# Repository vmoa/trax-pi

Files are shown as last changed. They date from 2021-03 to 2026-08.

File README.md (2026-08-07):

# T-Rax Raspberry Pi Notes

This is the Raspberry Pi implementation of the T-Rax roof controller for the Robert Ferguson Observatory
[rfo.org](https://rfo.org).

This design is a logical follow-on to the [Arduino T-Rax](https://github.com/votmoa/trax-arduino) roof controller
created back in 2017 by Jim Finn, David Kensiski and Jay Pacheco.  The switch to the Raspberry Pi was driven by the desire
to implement an [ASCOM Alpaca](https://ascom-standards.org/Developer/Alpaca.htm) interface so that the roof
can be opened via automation through tools such as [NINA](https://nighttime-imaging.eu/) and the now defunct [ACP](https://acpx.dc3.com/)

Testing insturctions can be found in the [test plan](doc/TestPlan.md) document.

Version history can be found in [VERSION.md](VERSION.md).

# Table of Contents

1. [Theory of Operation](#theory-of-operation)
1. [Detailed Design](#detailed-design)
1. [Hardware Design](#hardware-design)
1. [Future Plans](#future-plans)
1. [Installation](#installation)
1. [GPIO Notes](#gpio-notes)

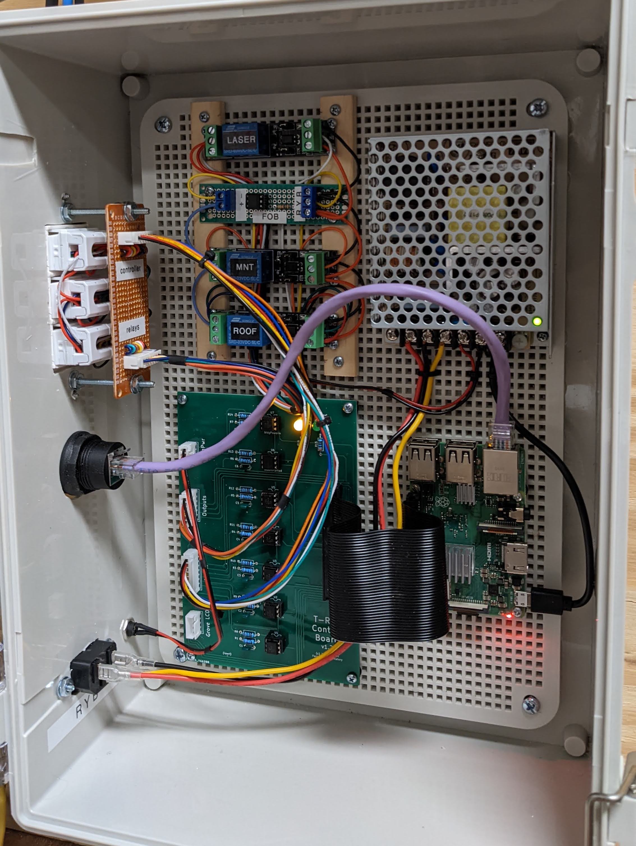
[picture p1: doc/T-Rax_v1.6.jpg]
T-Rax


# Theory of Operation

The server is written in Python 3 and utilizes only two external libraries:
[GPI Zero](https://gpiozero.readthedocs.io/en/stable/) to control the Raspberry Pi GPIO ports, and
[Flask](https://flask.palletsprojects.com/en/1.1.x/) to manage the web interface.  (Though Flask
has a bunch of prerequisites that also need to be loaded.)
The Browser panel is written in [HTML](https://www.w3schools.com/html/default.asp) using
Cascading Style Sheets ([CSS](https://www.w3schools.com/css/default.asp)) to control the apperance of the page, and
[Javascript](https://www.w3schools.com/js/default.asp) to handle communication and control the modal dialogs.

The overall software design is driven through interrupts -- there is no "main loop" as there was in the Arduino.
On start, the server sets  up logging, initializes each of the
GPIO pins, registers the web interface callbacks, then hands operation over to Flask to listen for incoming requests.

A separate bridge in `alpaca.py` exposes a minimal ASCOM Alpaca dome/shutter interface for automation clients. It accepts
`OpenShutter` and `CloseShutter` commands, reports `ShutterStatus`, and keeps control logic consistent with the browser
UI by routing Alpaca actuation through the same safety-checked roof toggle path.  Many thanks to
[Lena](https://github.com/lena-allie) for her [contributions](https://github.com/elenasch-playground/trax-pi/pull/1)
to the Alpaca driver.

There are three flavors of threads:

* Hardware input state changes trigger GPI Zero callbacks that execute in individual threads.
* Browser reqeusts trigger Flask actions that execute in separte threads.
* Finally an "update" thread executes every second to perform household chores.

There is a static html launcher page that is currently served directly by Apache.  This sets browser window size
(I don't think a window can reliably change its size once launched) and points it at http://trax:5000 which is where
trax.py is listening (by way of Flask).  This sends a template web page to paint the browser.  Once painted,
Javascript in the browser connects back to trax and and set up a server-sent events channel
([SSE](https://developer.mozilla.org/en-US/docs/Web/API/Server-sent_events))
so the server can pro-actively update the browser.  Browser javascript listens on this channel and paints the
display appropriately.  Browser buttons trigger async HTTP calls to varioius
trax URIs that perform an appropriate action, which in turn triggers an SSE response.

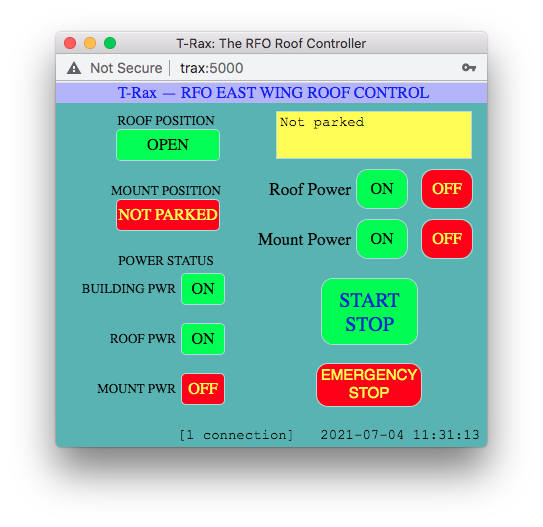
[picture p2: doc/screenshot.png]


Breaking this down, the connection flow is as follows:

1. User connects to http://trax and clicks the "Launch" button
1. Browser launches the T-Rax browser window pointing to http://trax:5000
1. Server sends static HTML, CSS and Javascript to paint the browser
1. After panting, browser javascript connects to http://trax:5000/connect to set up SSE channel

Then in normal operation:

* Server sends events via SSE when something changes
  * Browser executes javascript to handle the event
* Browser buttons send HTTP asynchronous requests to http://trax:5000/{whatever} to trigger actions
  * Sever performs the actions and responsds via SSE

The update thread is simply a thread that runs on startup to perform household chores and proactively update the
browser.  It then reschedules itself to run again one second later.  This thread updates the clock on the T-Rax
page to act as a hardbeat to confirm the server/browser SSE channel is active

# Software Design

The T-Rax software is structured around a Flask-based HTTP interface, GPIO abstractions, and a small set of cooperating threads.

* `trax.py` is the entry point. It initializes logging, constructs the GPIO objects, starts the periodic update thread, and registers the Flask routes for browser and Alpaca clients.
* `device.py` wraps `gpiozero` inputs and outputs in `Sensor` and `Control` classes. Inputs are configured with callbacks, and outputs include toggle timing and fob motion retry logic.
* `browser.py` implements the web UI callbacks. Each browser action checks safety interlocks, performs the required GPIO actuation, and sends status updates to the browser via SSE.
* `alpaca.py` implements a minimal ASCOM/Alpaca dome/shutter interface. It exposes `OpenShutter`, `CloseShutter`, `ShutterStatus`, discovery, and management endpoints while reusing the same roof safety and toggle logic as the browser UI.
* `sse.py` manages the server-sent event channel. The browser connects to `/connect` and receives live indicator updates, notices, and status changes.
* `test_mode.py` provides GPIO stubs for non-Pi environments so the software can run and be tested on a regular development machine.
* A recurring per-second housekeeping thread updates the browser clock, logs status, and handles timeouts (like laser auto-off).

Roof motion is coordinated by safety checks on building power, roof power, weather, mount park state, and the open/closed end-stop sensors. Both browser commands and Alpaca `OpenShutter`/`CloseShutter` flows delegate to the same underlying roof toggle path to keep behavior consistent.

# Hardware Design

The system is built around a [Raspberry Pi 3 B+](https://www.raspberrypi.org/products/raspberry-pi-3-model-b-plus/)
computer, though any Pi that sports the 40-pin GPIO header should work.  The header is routed to a custom circuit
board that splits out the GPIO inputs and outputs.  Output ports are fed to a 6-pin connetor that connects to the
relay board (see below).  Inputs are fed through RC low-pass filters (to reduce the effect
of electrical noise), current limiting resistors and optoisolators which ultimately deliver 3.3v to GPIO input ports.

External connectors are wired to jacks on a connecor board to maintain modularity.  Inputs are fed via an 8-pin
connector to the control board.  Outputs connect via a wiring harness from the 6-pin connector on the control board.
The roof and mount outputs directly feed relays to close a nomrally open circuit that in turn closes a relay circuit
in each of the remote roof and mount power controllers (not shown).

KiCad schematics and circuit board layout are available in the [KiCad](KiCad) subdirectory.
The full schematic is also available as a PDF: [TRax-Schematic.pdf](KiCad/TRax-Schematic.pdf)

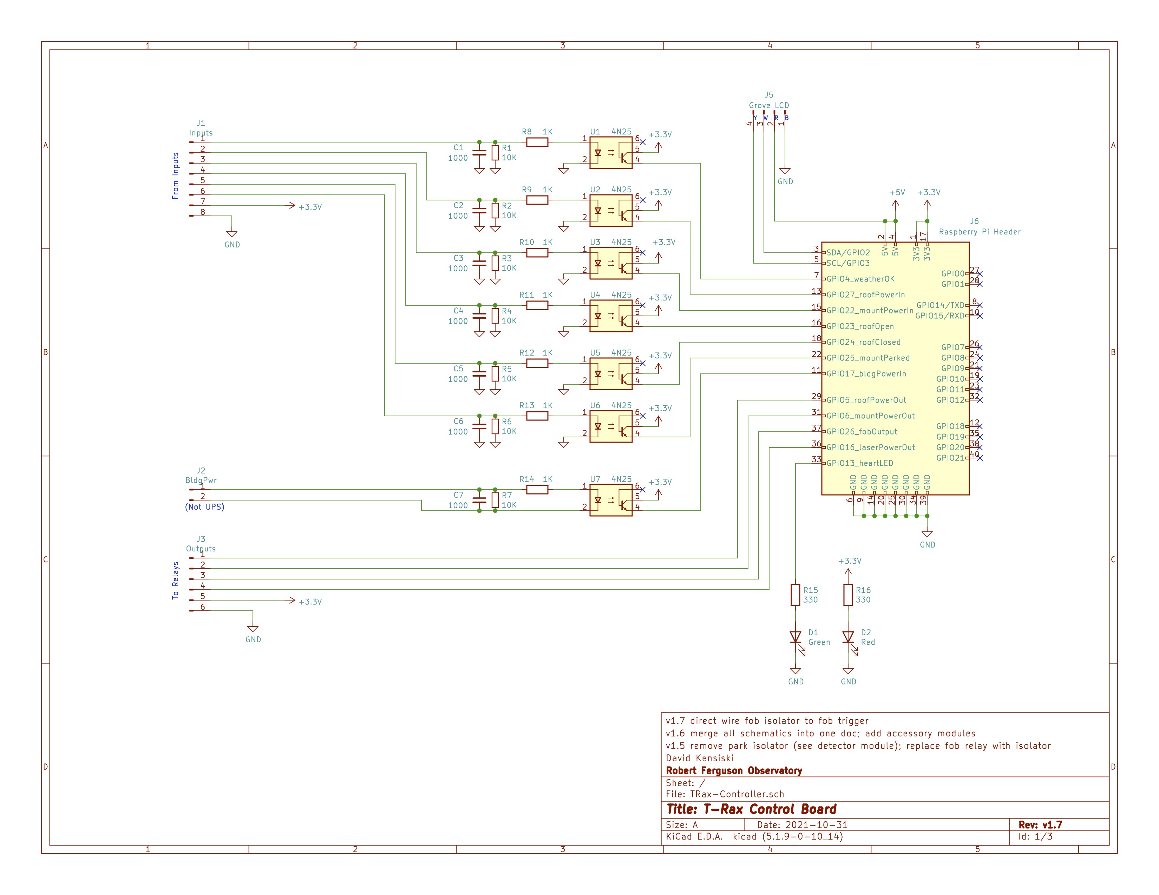
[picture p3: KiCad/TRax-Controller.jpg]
control board


### WeatherOK

This is the hardware signal from the [Boltwood Cloud Sensor](https://diffractionlimited.com/product/boltwood-cloud-sensor-ii/).
The configuration of the Clarity II software on the CCD PC determines what conditions trigger a weather alert.
The input feeds an optoisolator which triggers a GPIO port of the Raspberry Pi.  The Boltwood signal is active low
hence the name of the port is "weather OK".

### Mount Power

There are two ports used for the mount: mountPowerOut and mountPowerIn.  mountPowerOut triggers a
relay on the TRax Control Board which in turn closes a remote circuit in the Mount Power Controller under the telescope.
Power for that circuit comes from the Mount Power Controller.  The closing of that circuit triggers a relay in
the Mount Power Controller that powers the 12V supply that drives the mount.  A secondary contact on that relay 
closes the mountPowerIn circuit which is fed by 12V from the TRax Control Board.  That is fed through an optoisolator
to the GPIO port on the Raspberry Pi to provide positive feedback of mount power.

### Roof Power

Similarly there are two ports used for roof power: roofPowerOut and roofPowerIn.  These are designed
virtually identically to the mount power ports described above.

### Open / Close

Mounted on the roof rails are magnetic reed relays (alarm sensors) that engage when the roof is
either fully open or fully closed.  The TRax Control Board provides 12V to these relays through the Open/Close port.
Singal from these are fed through optoisolators to the GPIO ports on the Raspberry Pi.

### Fob

The fob is an actual gate controller fob (Model LM123) that has been removed from it's case and wired to a terminal
block.  T-Rax provides the fob with 12v DC to "replace" the battery, and has the contacts from it's top button wired
so we can trigger the fob on command.  This trigger was orignally wired to a relay but the contact bounce caused
the fob to trigger several times when the relay was engaged.  We instead use an optoisolator which avoids the
bounce, but care must be taken to maintain polarity with respect to the isolator.  The button is also an active
part of an RF circuit (433.92 MHz) so cable length should be limited.

### Park Detector

Because there is no place on the mount where physical relays can be mounted to postively confirm
park position, we have built a laser park sensor.  This consists of a low power laser on the mount dovetail plate and
a corresponding laser detector attached to the north wall.  These are aligned so that the detector triggers only when
the mount is in park position.  Both laser and detector are connected to the park port through an RJ-11 splitter.

The laser output from the control board triggers a relay with provides 12vdc (switched) to the park connector.
This 12v powers voltage regulators in both moduels that provides the 5v necessary to power the devices.  When
power is applied, the laser illuminates while simultaneously the park detector powers up.  If the telescope is
parked, the beam of the laser illuminates the detector.  The detector is active low so the signal is inverted by
a 2N2222 transistor and triggers an optoisolator which closes the park input.  If the telescope is not parked,
the laser does not illuminate the detector and the optoisolator output remains open.

Using 12v to power 5v circuitry avoids the issue of voltage drop over long DC runs that we've seen with the "friggin' laser".

### Building Power

Since TRax is fed via UPS power, the building power port is fed by a 12V wall wart plugged into
a non-UPS powered outlet.  When there is a power failure, this voltage drops and we are able to detect the outage to
prevent opening (but not closing!) of the roof.  The 12V is fed through an optoisolator to the GPIO port on the
Raspberry Pi.  It should be noted that this entire 12V source is isolated from the rest of the TRax circuit.  The
input side of the optoisolator is feed directly from this 12V source and (unlike the other circuits) is *not*
connected to the Control Board ground.

### Heart & Power LEDs

The heartbeat LED is fed directly from a GPIO port on the Raspberry Pi (through a current limiting resistor) and
flashes to indicate that the TRax software is running and healthy.  The power LED is fed by the 3.3V power rail on
the Raspberry Pi (thorugh a current limiting resistor) and indicates that the Raspberry Pi has power.

### Grove LCD

This port is wired for the [I2C](https://www.circuitbasics.com/basics-of-the-i2c-communication-protocol/)
serial bus required by the [Grove RGB LCD](https://wiki.seeedstudio.com/Grove-LCD_RGB_Backlight/).  We route the `SDA`
and `SCL` ports from the Raspberry Pi as well as the requisite ground and +5V.  Note that this uses +5V, not the +3.3V
of the rest of the controller.

As of this writing the Python code does not yet implement the Grove LCD.

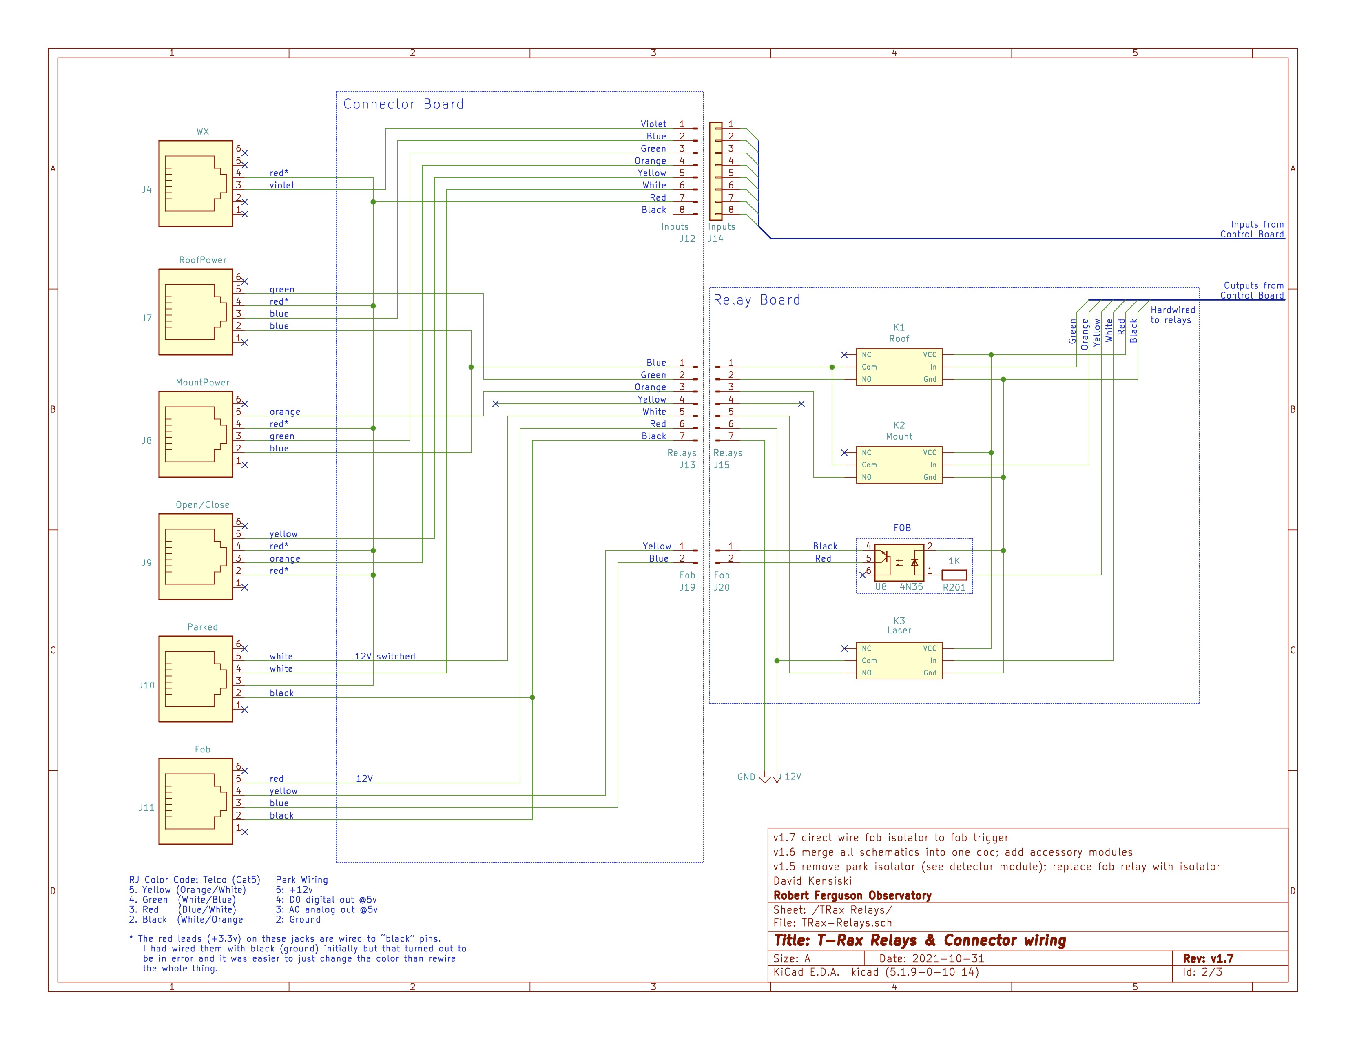
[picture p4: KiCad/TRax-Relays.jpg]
relay board


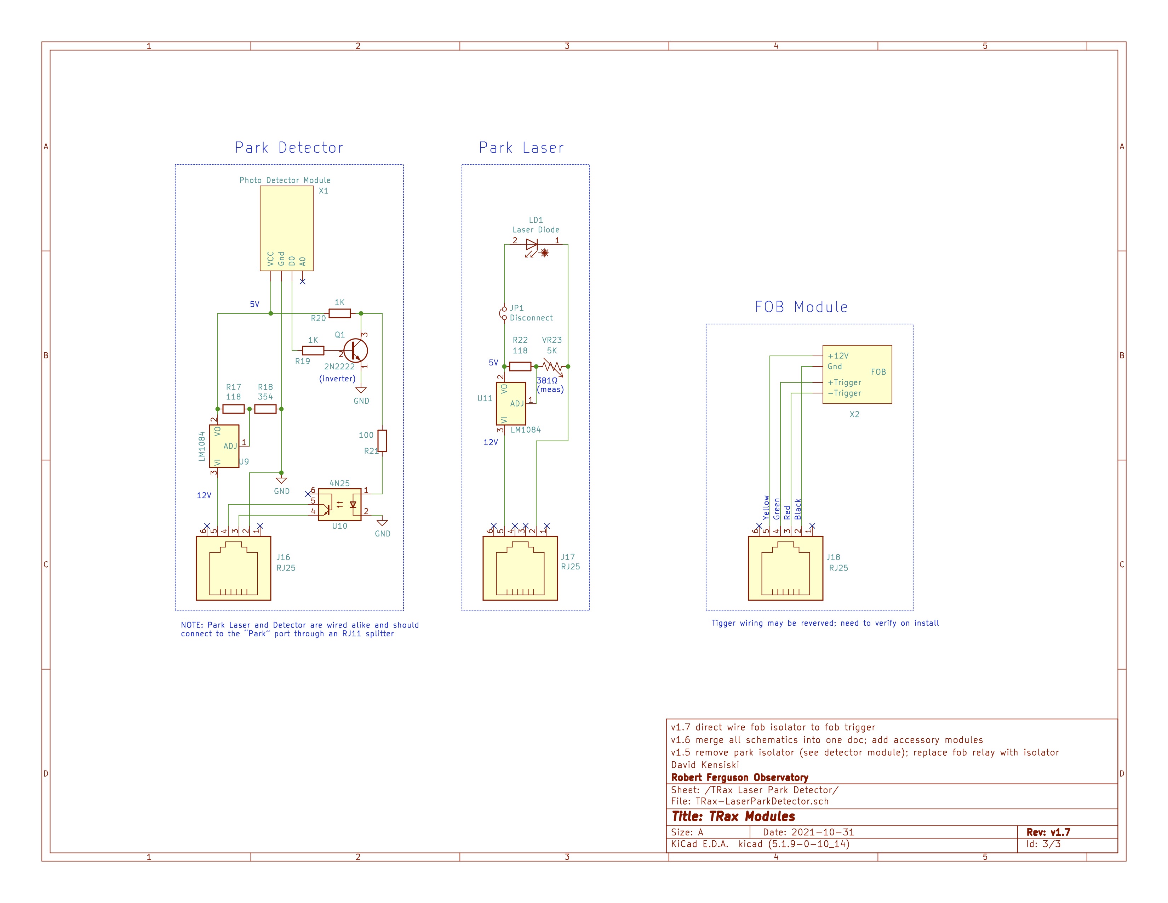
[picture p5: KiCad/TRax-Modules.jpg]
modules


# Future Plans

- [ ] Use md5 hashed password instead of hard coding
- [ ] Implement all logging using Flask's logging wrapper (evaluate how useful)
- [ ] Switch from Flask web server to Apache/WCGI
- [ ] Implement ASCOM/Alpaca
- [ ] Implement the Grove LCD
- [ ] Make multi-user (eg: for emergency override, notifications)

## Notes on the ASCOM/Alpaca implementation

From: Roger Boulanger <rogerjb88@gmail.com>\
Date: Fri, Sep 19, 2025 at 2:40 PM\
Subject: East Wing Automation.\
To: David Kensiski <David@kensiski.org>\

Hi Dave:

Following our brief discussion on this subject a couple days ago, I'd like to confirm a couple things.

First, T-Rax will need to include a Dome Alpaca Server which accepts "OpenShutter" and "CloseShutter" commands to open & close the roof.

In addition, it will need to expose the ShutterStaus ("ShutterOpen" or "ShutterClosed"). While NINA will send out Discord notifications for both conditions, it will only look for a "ShutterOpen" condition before attempting to do anything with the telescope.

How do you feel about having T-Rax automatically turning on Mount Power whenever the roof is fully open and off when it isn't? Otherwise we'd have to use one of the other standard ASCOM Dome commands to do this from NINA. Not impossible but just a little weird.

A benefit to SkyX users would be one less Checklist step to execute;-)

Roger

# Installation

Installation instructions reside in their own file: [INSTALL.md](INSTALL.md)

# GPIO Notes

General Purpose Input/Output

GPIO Pinout Diagram


## Input GPIO ports (sensors)

* GPIO4: weatherOK = newSensor(pin=4);
* GPIO17: bldgPowerIn = newSensor(pin=17);
* GPIO27: roofPowerIn = newSensor(pin=27);
* GPIO22: mountPowerIn = newSensor(pin=22);
* GPIO23: roofOpen = newSensor(pin=23);
* GPIO24: roofClosed = newSensor(pin=24);
* GPIO25: mountParked = newSensor(pin=25);

## Output GPIO ports (controls)

* GPIO5: roofPowerOut = newControl(pin=5)
* GPIO6: mountPowerOut = newControl(pin=6)
* GPIO26: fobOutput = newControl(pin=26)
* GPIO13: heartLed = newControl(pin=13)
* GPIO16: laserPowerOut = newControl(pin=16)

| GPIO | Function | T-Rax |
| ---- | --- | ----- |
| 2 | I2C | LCD |
| 3 | I2C | LCD |
| 4 | | weatherOK |
| 17 | SPI1 | bldgPowerIn |
| 27 | | roofPowerIn |
| 22 | | mountPowerIn |
| 10 | SPI0 |  |
| 9 | SPI0 |  |
| 11 | SPI0 |  |
| 0 | I2C | LCD |
| 5 | | roofPowerOut |
| 6 | | mountPowerOut |
| 13 | PWM | Heart LED |
| 19 | PWM,SPI1 |  |
| 26 | | fobOutput |
| | | |
| 14 | Serial |  |
| 15 | Serial |  |
| 18 | PWM,SPI1 |  |
| 23 | | roofOpen |
| 24 | | roofClosed |
| 25 | | mountParked |
| 8 | SPI0 |  |
| 7 | SPI0 |  |
| 1 | I2C | LCD |
| 12 | PWM |  |
| 16 | SPI1 | laserPowerOut |
| 20 | SPI1 |  |
| 21 | SPI1 |  |

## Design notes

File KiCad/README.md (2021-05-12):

# KiCad Files

[KiCad](https://kicad.org/) (pronounced KEY-cad) is a Cross Platform and Open Source Electronics Design Automation Suite.

This directory contains the design files for the TRax hardware. Source is KiCad but I have exported as PDF/JPG.

* **TRax-BlockDiagram** Work in progress to document the overall system
* **TRax-Controller** Schematic and PCB layout of the controller board
* **TRax-Relays** TRax relays and connector woring

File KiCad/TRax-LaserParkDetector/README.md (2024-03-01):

# Park Detector KiCad files

This is a static copy of the [TRax-Schematic](../TRax-Schematic) project at v1.7 with everythig stripped
out except for the park detector.  Reason being that KiCad doesn't appear to have a way to lay out a board
based on only part of a schematic.

**Caveat Emptor**: Changes made to the main schematic will have to be replicated here.  (Boo...)

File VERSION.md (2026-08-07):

# T-Rax Version History

| Version | Date | Notes |
|---|---|---|
| v.1.1.0 | 2026-08-06 | Add ASCOM Alpaca dome/shutter interface |
| v.1.0.8 | 2023-06-21 | Implement laser timeout for Emergency Override |
| v.1.0.7 | 2021-10-17 | Fixed toggleFob() roof logic |
| | | Increased fob_wait to 3 seconds |
| | | Better roof position reporting |
| | | Added "confused" roof state |
| v.1.0.6 | 2021-09-28 | Replace toggleThrice() with fob.toggleFob(), using callbacks instead of a timer loop |
| v.1.0.5 | 2021-08-22 | In emergency override, checkPark toggles laser indefinitely, and updateBrowser reports actual park position |
| v.1.0.4 | 2021-07-11 | Added toggleThrice() to make sure fob activates roof |
| | | Updated installation instructions |
| v.1.0.3 | 2021-07-07 | Removed pedantic power checks |
| | | Created test plan |
| | | mount and roof should not be reverse logic |
| | | pulled custom relay symbol into library |
| | | pass version to browser and report on connect |
| v.1.0.2 | 2021-06-05 | created service start script |
| | | added connection count to ticker |
| | | add file locking to prevent multiple copiesA |
| | | lots of documentation updates |
| | | lots of schematic updates |
| v.1.0 | 2021-04-25 | Released version 1.0; see `git log` for previous |

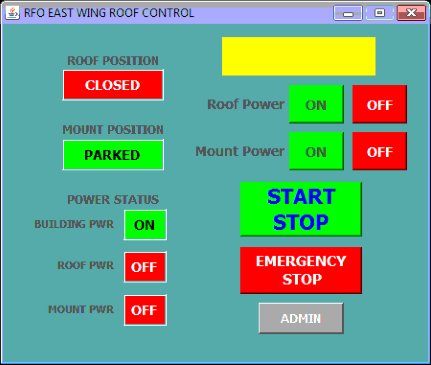
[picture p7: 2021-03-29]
doc/java.png

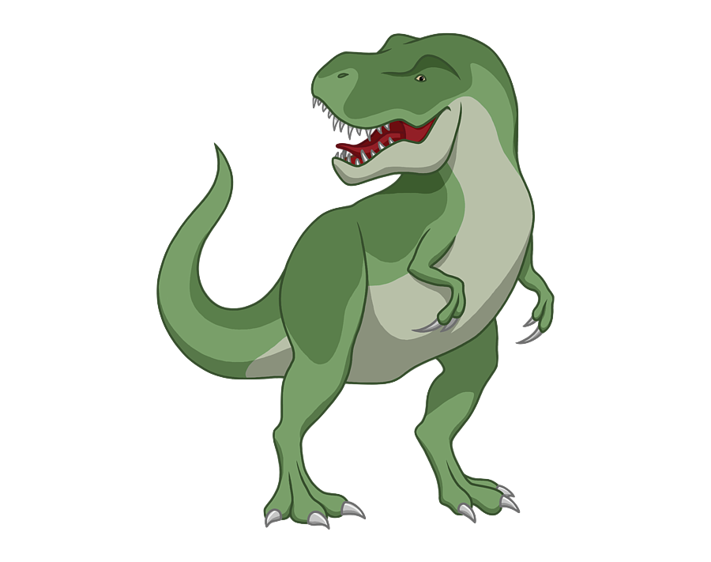
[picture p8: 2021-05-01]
static/trex-clipart.png

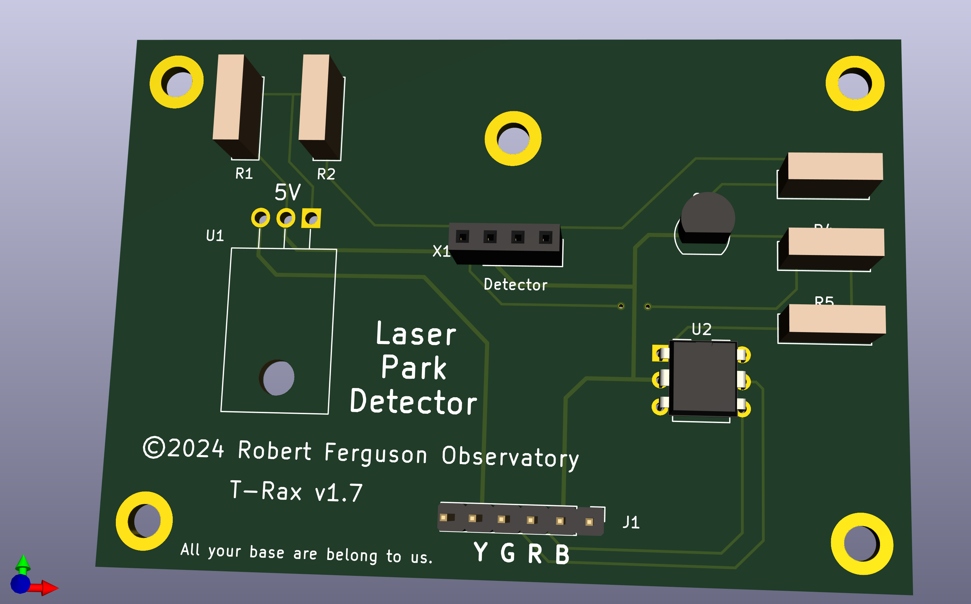
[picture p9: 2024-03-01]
KiCad/ParkDetector_3d.png

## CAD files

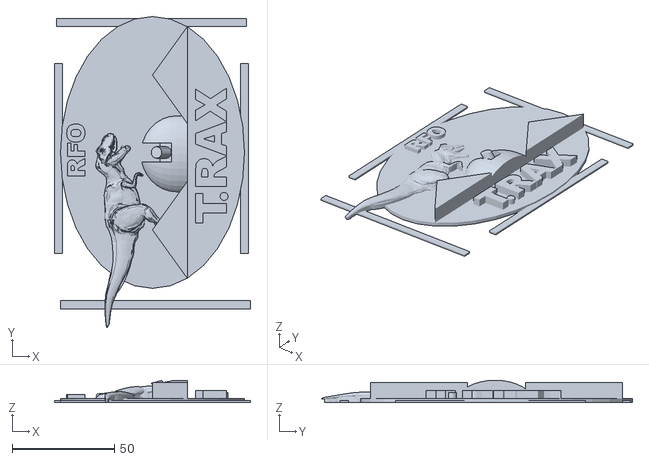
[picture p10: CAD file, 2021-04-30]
doc/3d_print/rfo.stl
96.0 x 152.1 x 11.0

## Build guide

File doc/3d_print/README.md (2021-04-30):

# 3D Printer Design for T-Rax Logo

These designs were produced and 3D printed by Aaron "Jay" Pacheco (joaquemin@gmail.com) for the
original Arduino T-Rax. He has since moved away but has graciously shared them with us.

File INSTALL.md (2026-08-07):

# Installation Notes

* Burn an SD card from a Rapberry Pi OS (32-bit) image

* Boot and configure; recommendations:
  * **Wired network**, wifi okay for testing
  * **Static IP** or statically assigned DHCP
  * **Local timezone** (logs easier to parse)

* Further configuration: `sudo raspi-config`
  * Set hostname: System Options --> Hostname
  * Enable SSH: Interface Options --> SSH
  * Disable graphical interface: System Options --> Boot / Auto Login --> Console
    * Optional, but recommended for production

* Change system editor to vim; nano should die
```
sudo update-alternatives --set editor /usr/bin/vim.tiny
```

* Update system
```
sudo apt-get update
sudo apt-get upgrade
```

* Install prerequisites
```
sudo apt-get install apache2
```

* Create trax user
```
sudo useradd -d /home/trax -s /bin/bash -m trax
sudo usermod -G gpio trax
```

* Fetch trax code
```
cd /home/trax
sudo -u trax git clone https://github.com/vmoa/trax-pi.git
```

* Clean up stuff that should be part of a trax setup script
```
sudo touch /tmp/trax.lock 
sudo chmod 666 /tmp/trax.lock 
sudo touch /var/log/trax.log
sudo chown trax /var/log/trax.log
#
sudo cp /home/trax/trax-pi/static/index.html /var/www/html/
sudo cp /home/trax/trax-pi/static/trex-clipart.png /var/www/html/
#
sudo cp /home/trax/trax-pi/static/trax.service /etc/systemd/system/
sudo systemctl enable trax.service
sudo systemctl start trax.service
```

* RFO specific stuff
  * Add an admin user or two with SSH credentials (TODO)
  * Configure static route for VPN (TODO)

* Point a browser at your system and verify!

* Reboot and verify auto-start
```
sudo reboot
```

# Appendix

* Debugging commands if things go south
```
systemctl status trax.service
systemctl list-units | grep trax
journalctl -u trax.service
```

* Add another user
```
NEWUSER=dlk
sudo useradd -d /home/$NEWUSER -s /bin/bash -m $NEWUSER
sudo usermod -G adm,gpio,sudo $NEWUSER
sudo passwd $NEWUSER
sudo -u $NEWUSER mkdir ~$NEWUSER/.ssh
sudo -u $NEWUSER vi ~$NEWUSER/.ssh/authorized_keys
sudo -u $NEWUSER chmod 700 ~$NEWUSER/.ssh
```

# Alpaca (ASCOM) API

This project exposes a minimal ASCOM Alpaca-compatible dome interface (shutter-only) at `/api/v1/dome/0`.

Quick test examples (once `trax` is running):

```
# Check connected
curl http://<host>:5000/api/v1/dome/0/connected

# Open shutter
curl http://<host>:5000/api/v1/dome/0/openshutter

# Close shutter
curl http://<host>:5000/api/v1/dome/0/closeshutter

# Query shutter status (ASCOM ShutterState enum: 0=Open, 1=Closed, 2=Opening, 3=Closing, 4=Error)
curl http://<host>:5000/api/v1/dome/0/shutterstatus
```

The API returns JSON in the Alpaca format with `Value`, `ClientTransactionID`, `ServerTransactionID`, `ErrorNumber`, and `ErrorMessage` fields.

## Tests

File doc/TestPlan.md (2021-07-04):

# Instructions for Testing T-Rax

This is a test suite to run through to check for regressions when making
changes to the T-Rax code.  This requires the simulator and should work
with it either connected through the RJ11 cables or directly to the
controller board.
(Note that instrucitons were initally written using the sensor cables and
have not yet been tested with the direct controller connection.)

[Return](../README.md) to the T-Rax main page.

---

_TODO_: Add wiring details and options

Note on `BldgPwr`: The pushbutton switch is used when connecting directly to the controller board;
the toggle is used when connecting via sensor cables.

1. Start the version of trax.py you wish to test.
   * This might require stopping the auto-boot version:
      `sudo systemctl stop trax`
   * Simulator mode gives you more time to push buttons:
      `sudo ./trax.py --simulator`

1. Set all simulator buttons and switches to __OFF__ (including `BldgPwr` toggle)

1. Point a browser to http://trax (or via IP) and click the image to open T-Rax browser window
   * Notice briefly reads `Connecting to T-Rax`, then `Connected!` and a welcome and version number
   * Roof position reads `MIDWAY`
   * Mount position reads `UNKNOWN`
   * All status indicators read `OFF`
   * Time should be incrementing

1. Depress "Close" button
   * ROOF POSITION reads `CLOSED`

1. Turn `BldgPwr` __ON__
   * BUILDING PWR reads `ON`

1. Click MOUNT POSITION `UNKNOWN` indicator
   * Notice reads `Laser ON checking park`
   * Park LED (red) illuminates briefly
   * After _simulatordelay_ seconds, LED turns off and
     * Notice reads `Not parked`
     * MOUNT POSITION reads `NOT PARKED`
   * After _shortdelay_ seconds, MOUNT POSITION background changes to orange
   * After _longdelay_ seconds, MOUNT POSITION changes to `UNKNOWN`

1. Click MOUNT POSITION `UNKNOWN` indicator
   * Notice reads `Laser ON checking park`
   * Park LED (red) illuminates briefly
   * While LED illuminated, depress "Park" button (repeat if you missed it)
     * Park LED turns off
     * Notice reads `Parked`
     * MOUNT POSITION reads `PARKED`
   * After _shortdelay_ seconds, MOUNT POSITION background changes to pale yellow
   * After _longdelay_ seconds, MOUNT POSITION changes to `UNKNOWN`

1. Click `START STOP`
   * Noice reads `Cannot open roof: roof power is not on`

1. Click Roof Power `ON`
   * Notice reads `Turning on roof power`
   * RoofPwr LED (yellow) illuminates

1. Depress "RoofPwr" button
   * ROOF PWR reads `ON`

1. Click Mount Power `ON`
   * Notice reads `Cannot turn on mount: roof is not open`

1. Click `START STOP`
   * Notice reads `Cannot open roof: Weather not OK`

1. Depress "WX" button

1. Click `START STOP`
   * Notice flashes `Laser ON checking park` and Park LED (red) illuminates briefly
     (might be too fast to notice, but we tested above)
   * MOUNT POSITION reads `PARKED`
   * Noitce reads `Toggling fob (opening roof)`
   * FOB LED (blue) illuminates briefly
   * A lot of things happen at once -- repeat this step as necessary to confirm operation

1. Undpress "Close" button
   * ROOF POSITION reads `MIDWAY`

1. Click `START STOP`
   * Notice reads `Toggling fob (roof midway)`
   * FOB LED (blue) illuminates briefly

1. Click `EMERGENCY STOP`
   * Notice reads `EMERGENCY STOP! Turning off roof power`
   * RoofPwr LED (red) extinguishes

1. Undepress RoofPwr button
   * ROOF PWR reads `OFF`

1. Click Roof Power `ON`
   * Notice reads `Turning on roof power`
   * RoofPwr LED (red) extinguishes

1. Depress RoofPwr button
   * ROOF PWR reads `ON`

1. Depress "Open" button
   * ROOF POSITION reads `OPEN`

1. Click Mount Power `ON`
   * Notice reads `Turning on mount power`
   * MntPwr LED (green) illuminates

1. Depress "MntPwr" button
   * MOUNT PWR reads `ON`

1. Undepress "Park" button

1. Click `START STOP`
   * Notice reads `Laser ON checking park` and Park LED (red) illuminates
   * After _shortdelay_ seconds, MOUNT POSITION reads `NOT PARKED`
   * Notice reads `Cannot close roof: mount must be parked first`

1. Depress "Park" button

1. Click `START STOP`
   * Notice flashes `Laser ON checking park` and Park LED (red) illuminates briefly, MOUNT POSITION reads `PARKED`
   * Notice reads `Cannot close roof: mount power is on`

1. Click Mount Power `OFF`
   * MntPwr LED (yellow) turns off

1. Undepress "MntPwr" button

1. Click `START STOP`
   * Notice flashes `Laser ON checking park` and Park LED (red) illuminates briefly,  MOUNT POSITION reads `PARKED`
   * Noitce reads `Toggling fob (closing roof)`
   * FOB LED (blue) illuminates briefly

1. Undepress "Open" button
   * ROOF POSITION reads `MIDWAY`

1. Depress "Close" button
   * ROOF POSITION reads `CLOSED`

1. Click Roof Power `OFF`
   * RoofPwr LED extinguishes

1. Undepress "RoofPwr" button
   * ROOF PWR read `OFF`

1. Stop the test version of the software by typing Ctrl-C in the shell where you started it
   * Restart the auto-start version if stopped above: 
      `sudo systemctl start trax`

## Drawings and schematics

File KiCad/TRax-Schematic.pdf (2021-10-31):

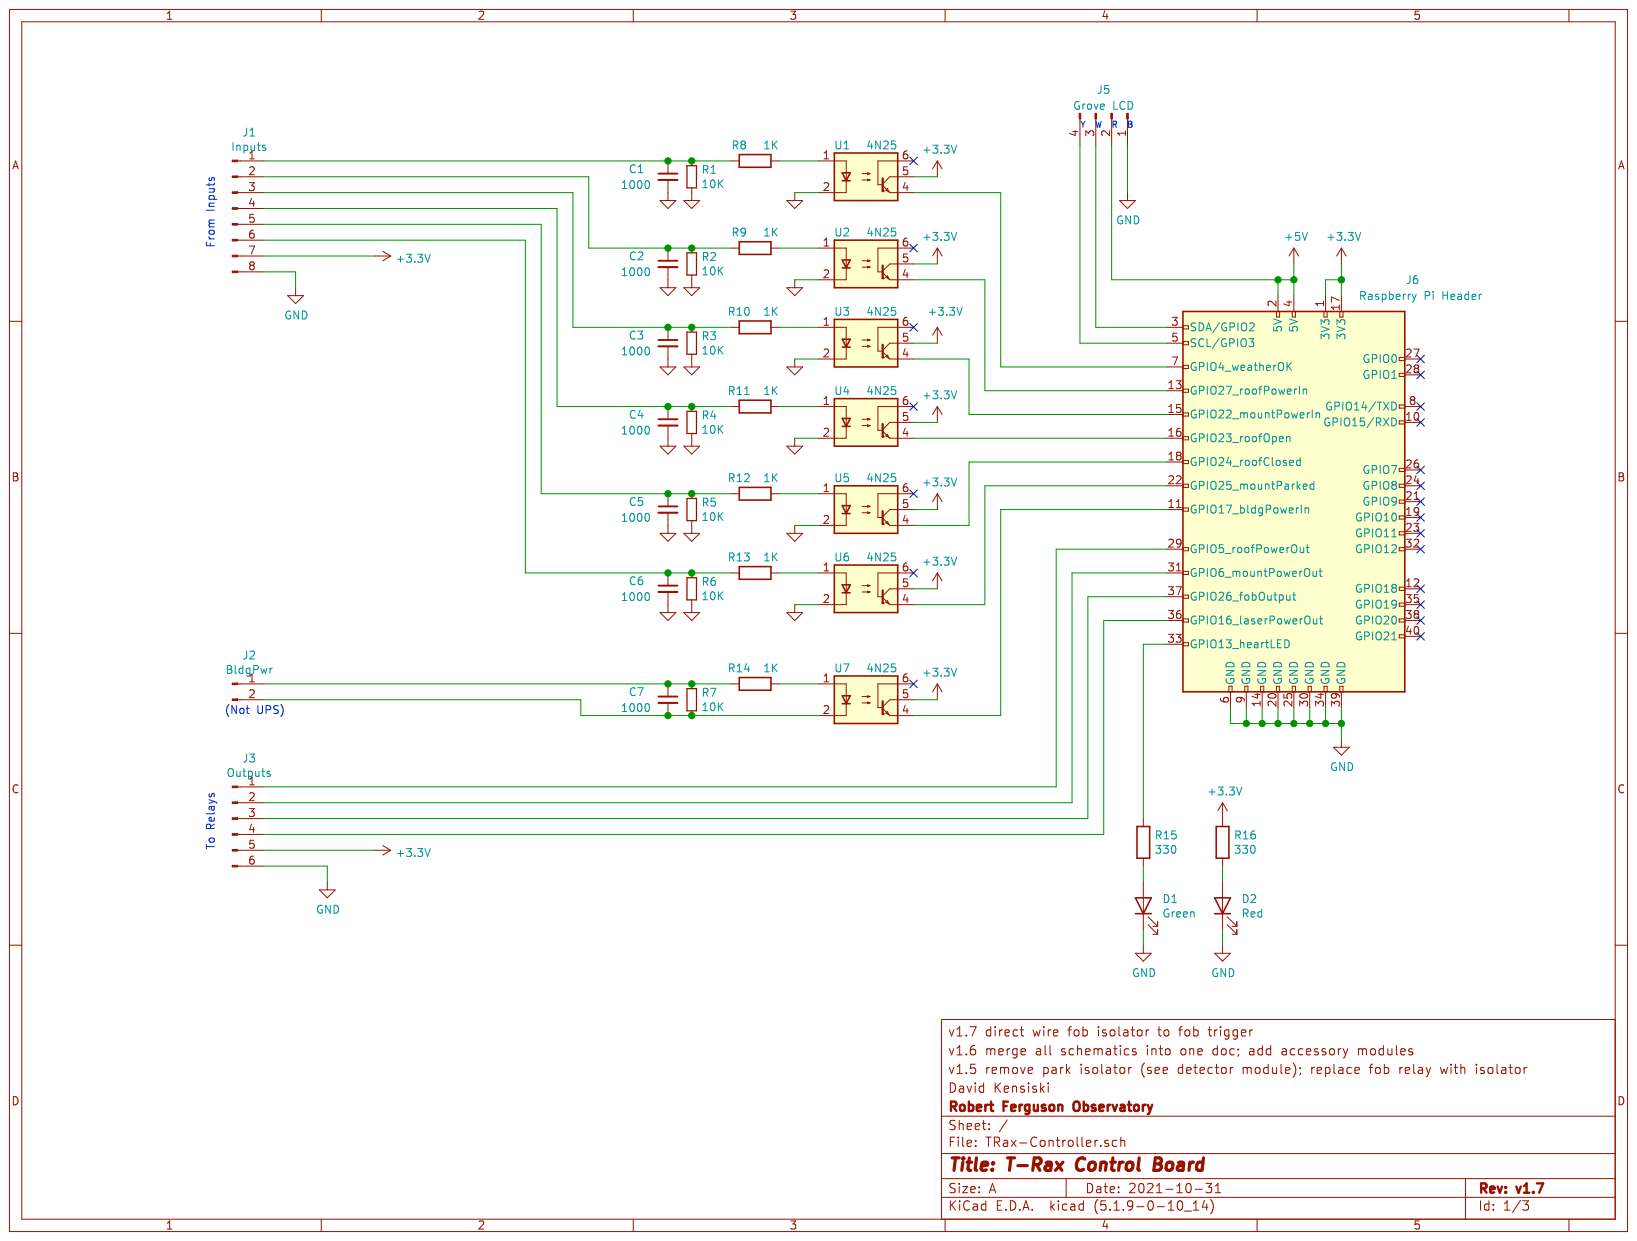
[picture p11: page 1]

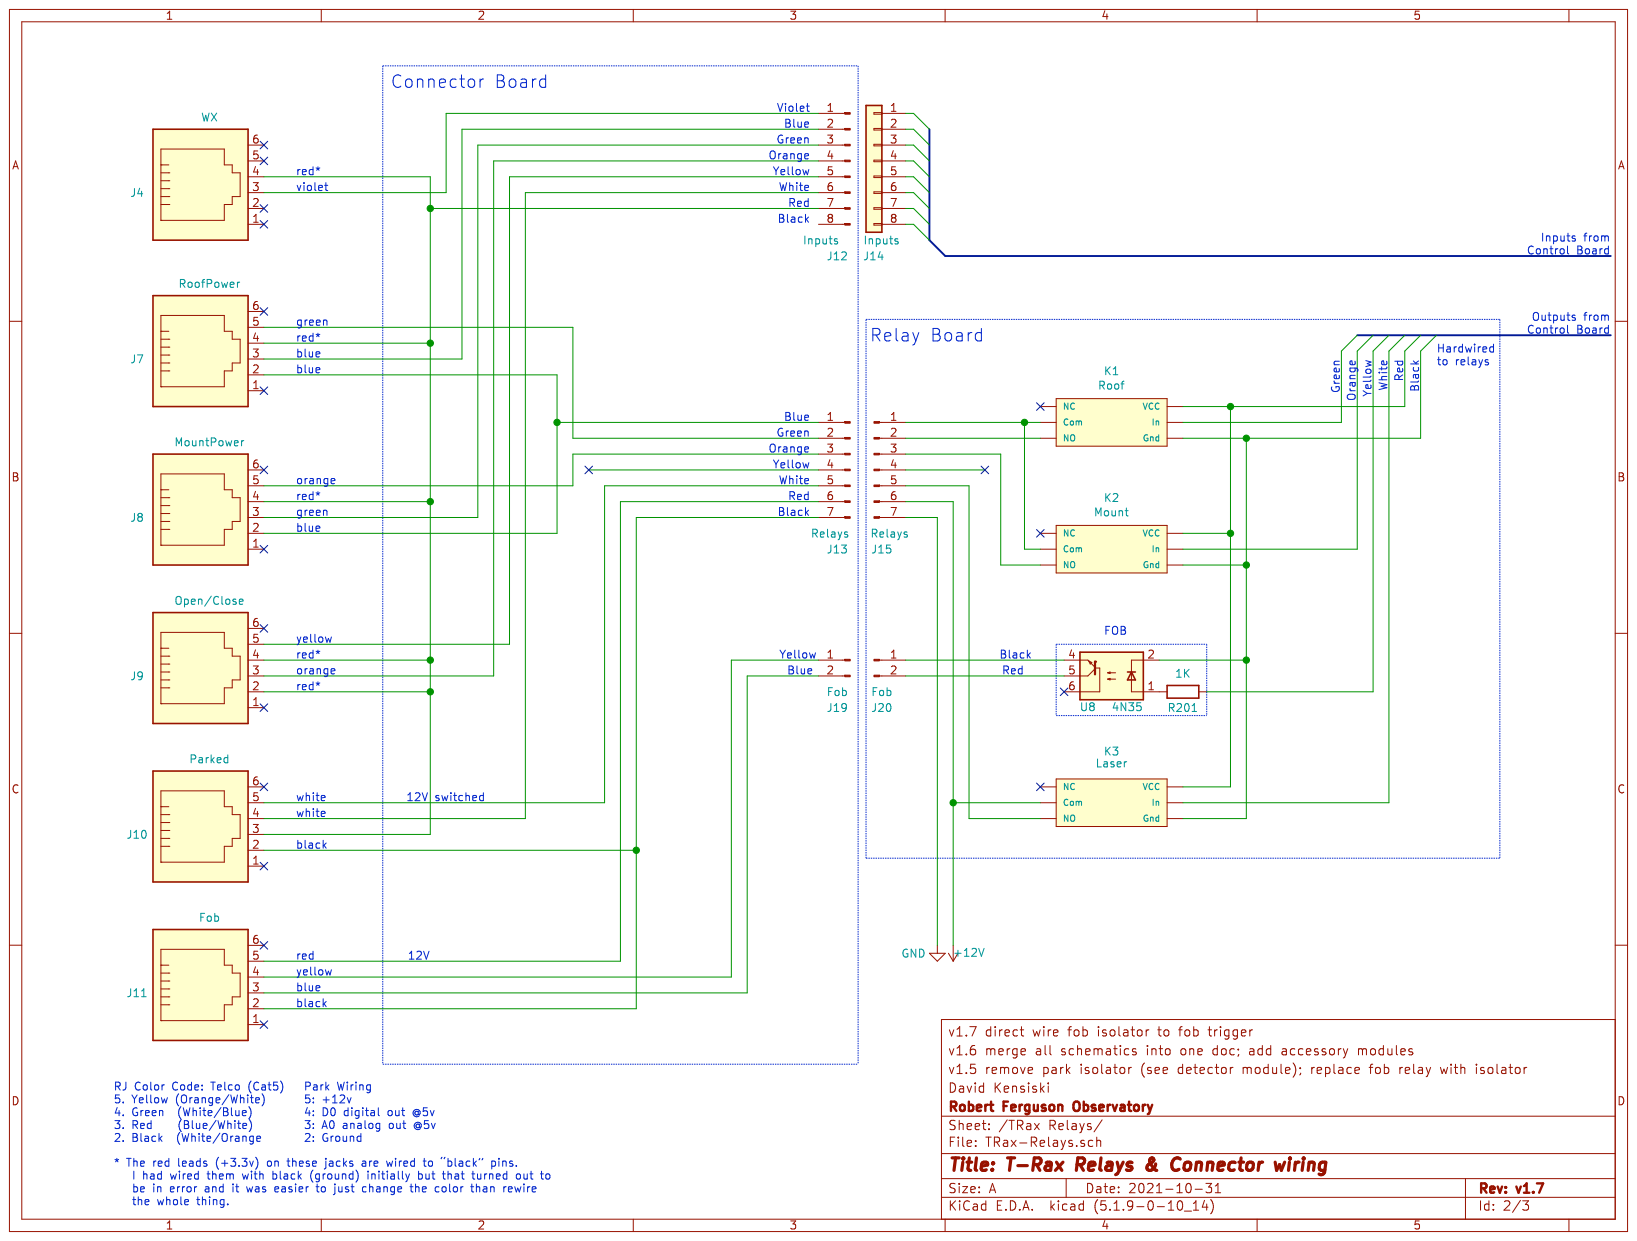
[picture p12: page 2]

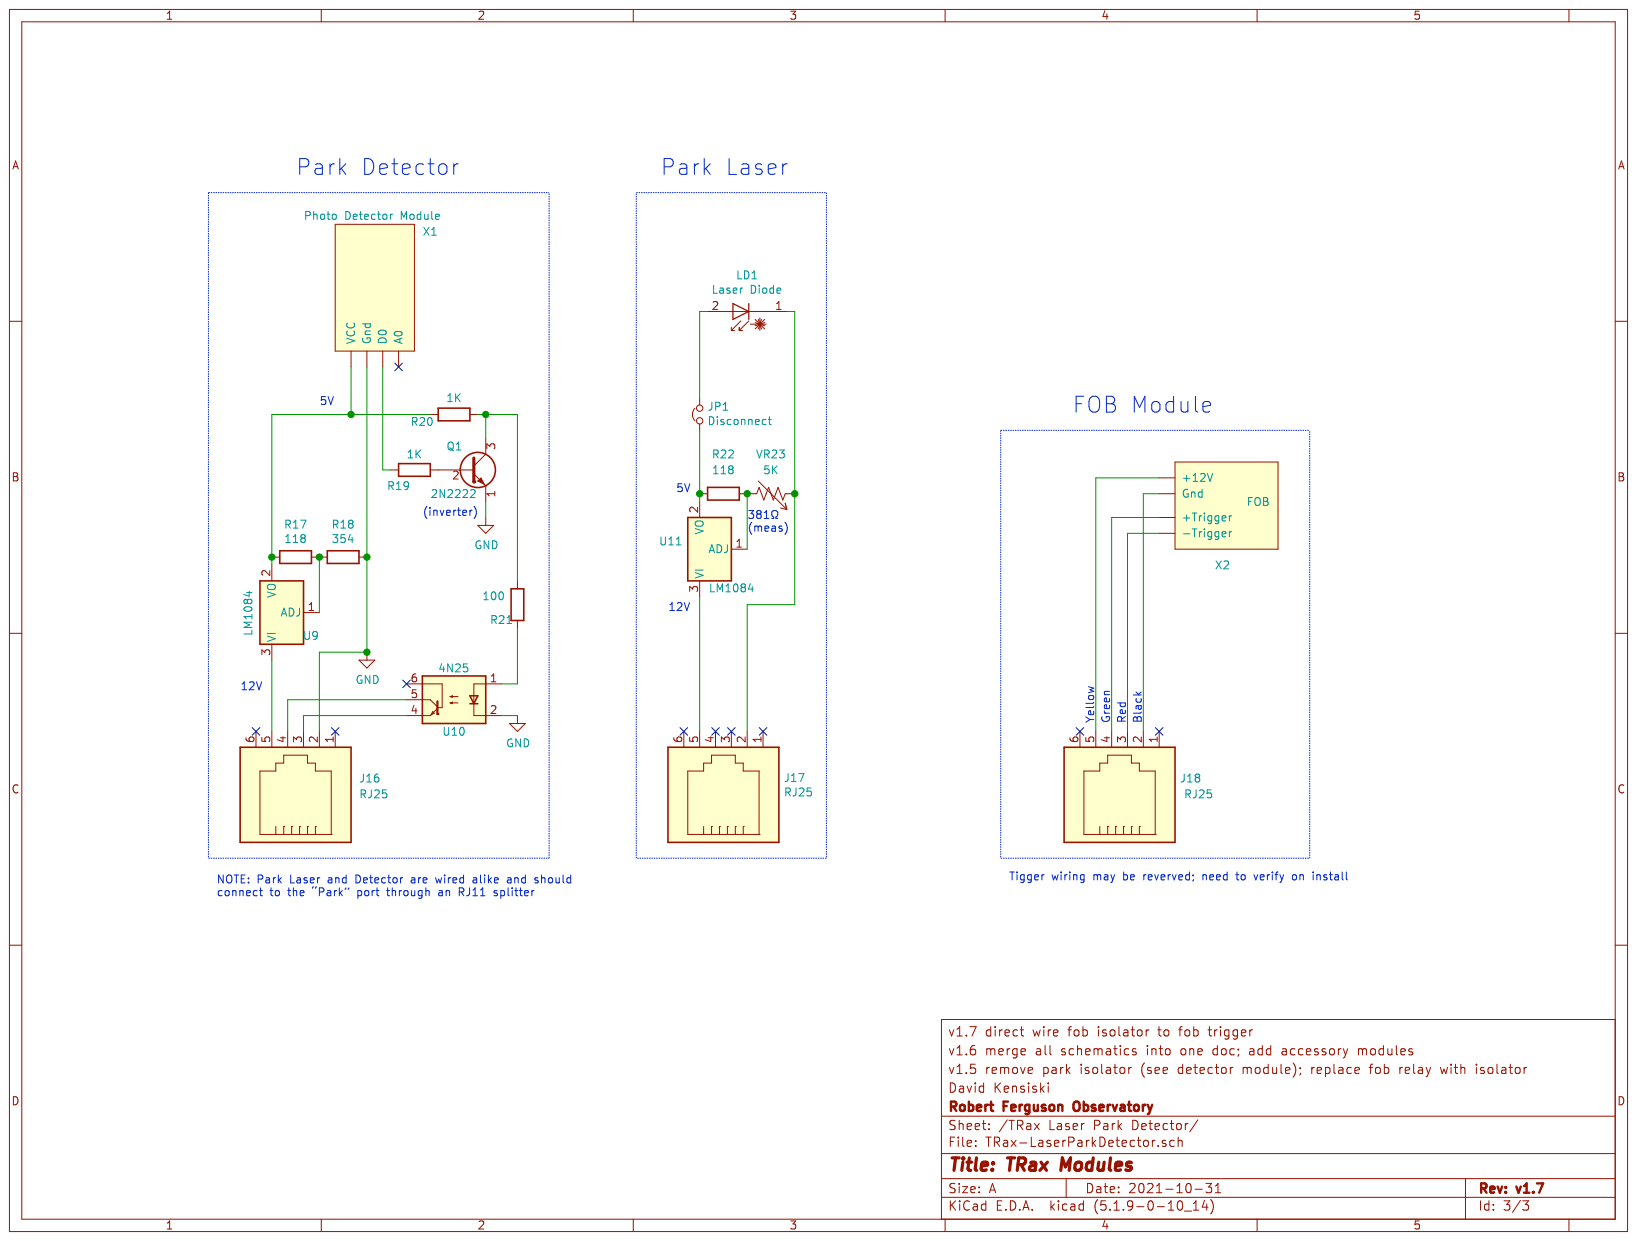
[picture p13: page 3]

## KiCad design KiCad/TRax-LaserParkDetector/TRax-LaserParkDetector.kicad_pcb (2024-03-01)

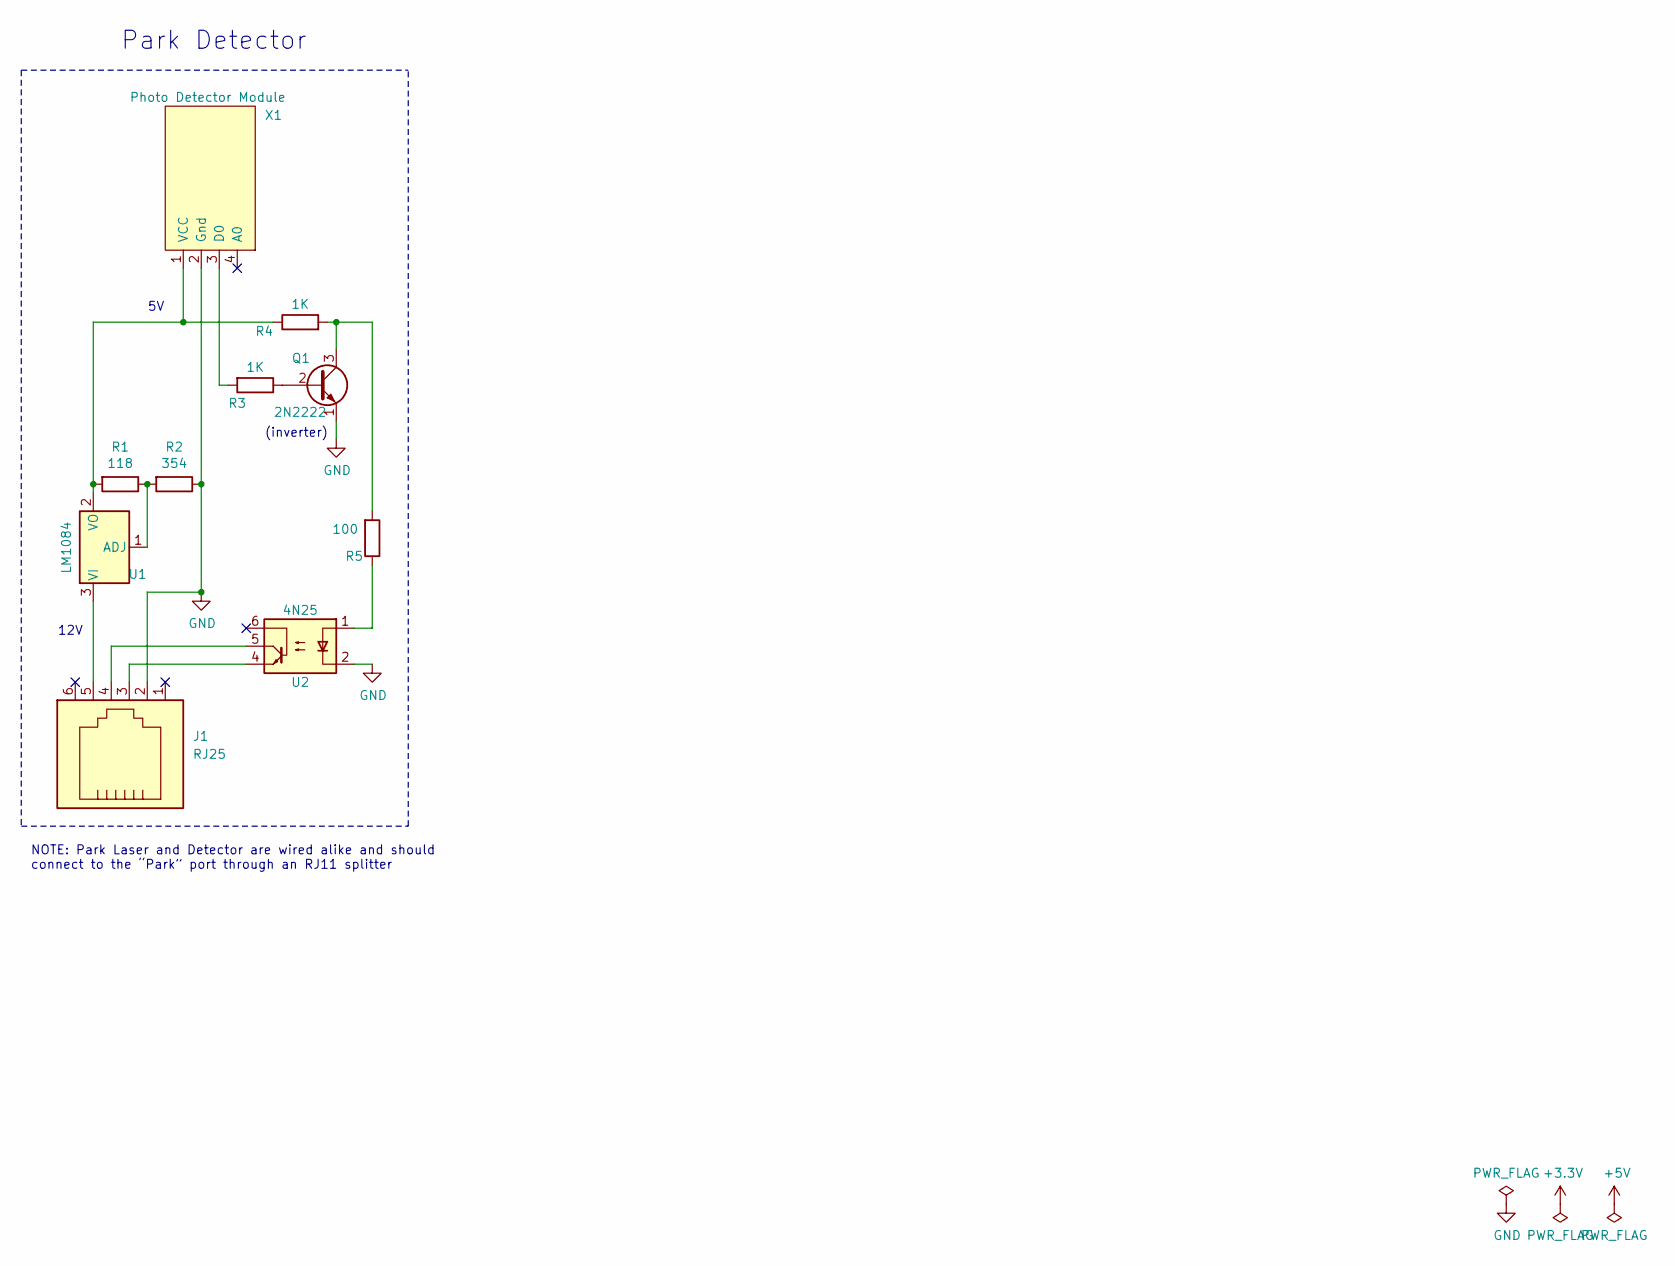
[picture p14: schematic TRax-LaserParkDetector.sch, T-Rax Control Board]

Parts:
J1: RJ25; PinHeader_1x06_P2.54mm_Vertical
Q1: 2N2222; TO-92_Inline
R1: 118; R_Box_L8.4mm_W2.5mm_P5.08mm
R2: 354; R_Box_L8.4mm_W2.5mm_P5.08mm
R3, R4: 1K; R_Box_L8.4mm_W2.5mm_P5.08mm
R5: 100; R_Box_L8.4mm_W2.5mm_P5.08mm
U1: LM1084; TO-220F-3_Vertical
U2: 4N25; DIP-6_W7.62mm
X1: Photo Detector Module; PhotoDetectorModule

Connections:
GND: J1.2, Q1.1 (E), R2.1, U2.2, X1.2 (Gnd)
unnamed: J1.3, U2.4
unnamed: J1.4, U2.5
unnamed: J1.5, U1.3 (VI)
unnamed: Q1.2 (B), R3.1
unnamed: Q1.3 (C), R4.2, R5.2
unnamed: R1.1, R2.2, U1.1 (ADJ)
unnamed: R1.2, R4.1, U1.2 (VO), X1.1 (VCC)
unnamed: R3.2, X1.3 (D0)
unnamed: R5.1, U2.1

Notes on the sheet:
Park Detector
12V
(inverter)
NOTE: Park Laser and Detector are wired alike and should connect to the “Park” port through an RJ11 splitter

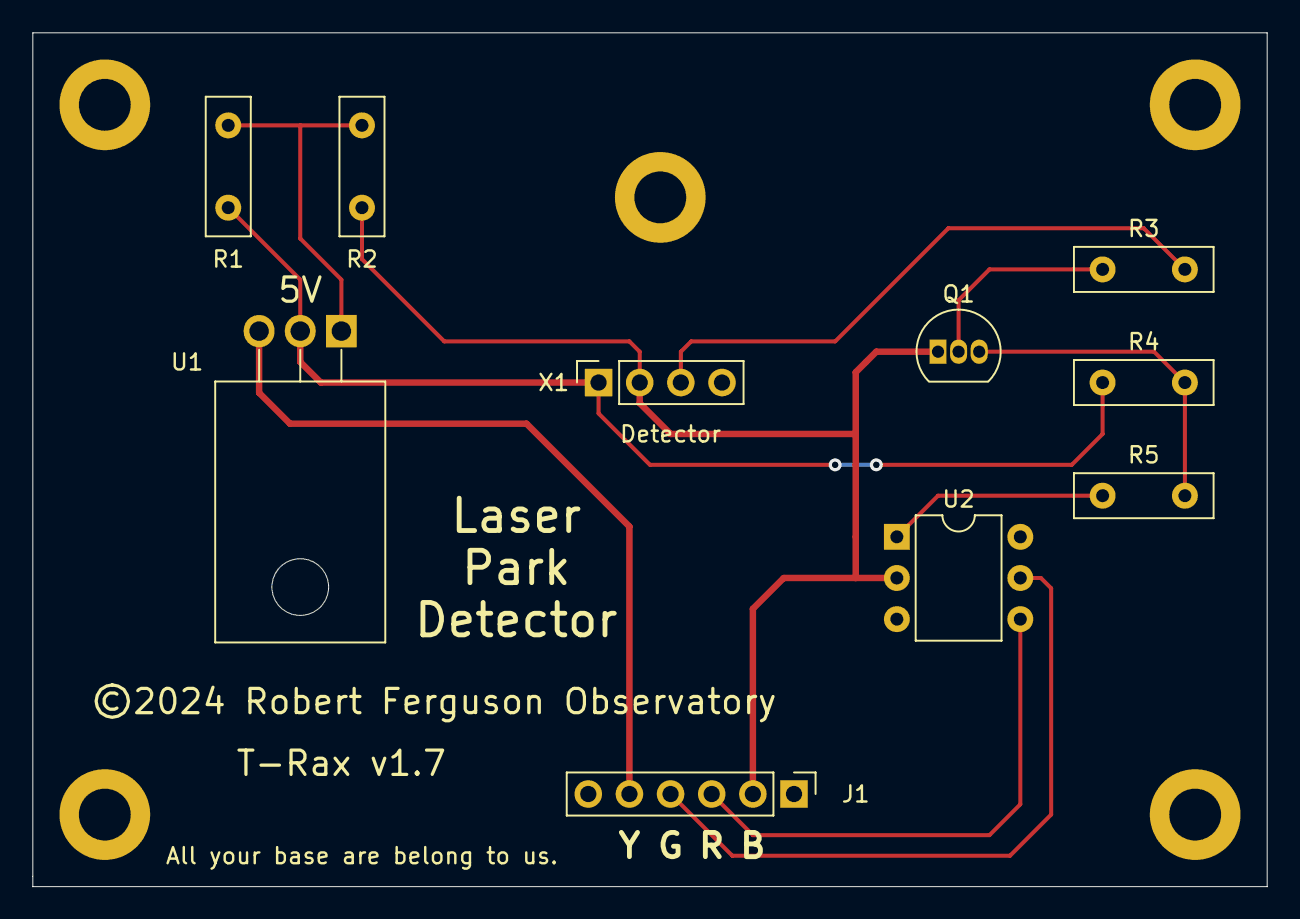
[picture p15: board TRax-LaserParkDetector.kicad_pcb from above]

Board: 2 copper layers, 76.2 x 52.7 mm, 10 parts (0 on the bottom side), 10 nets.

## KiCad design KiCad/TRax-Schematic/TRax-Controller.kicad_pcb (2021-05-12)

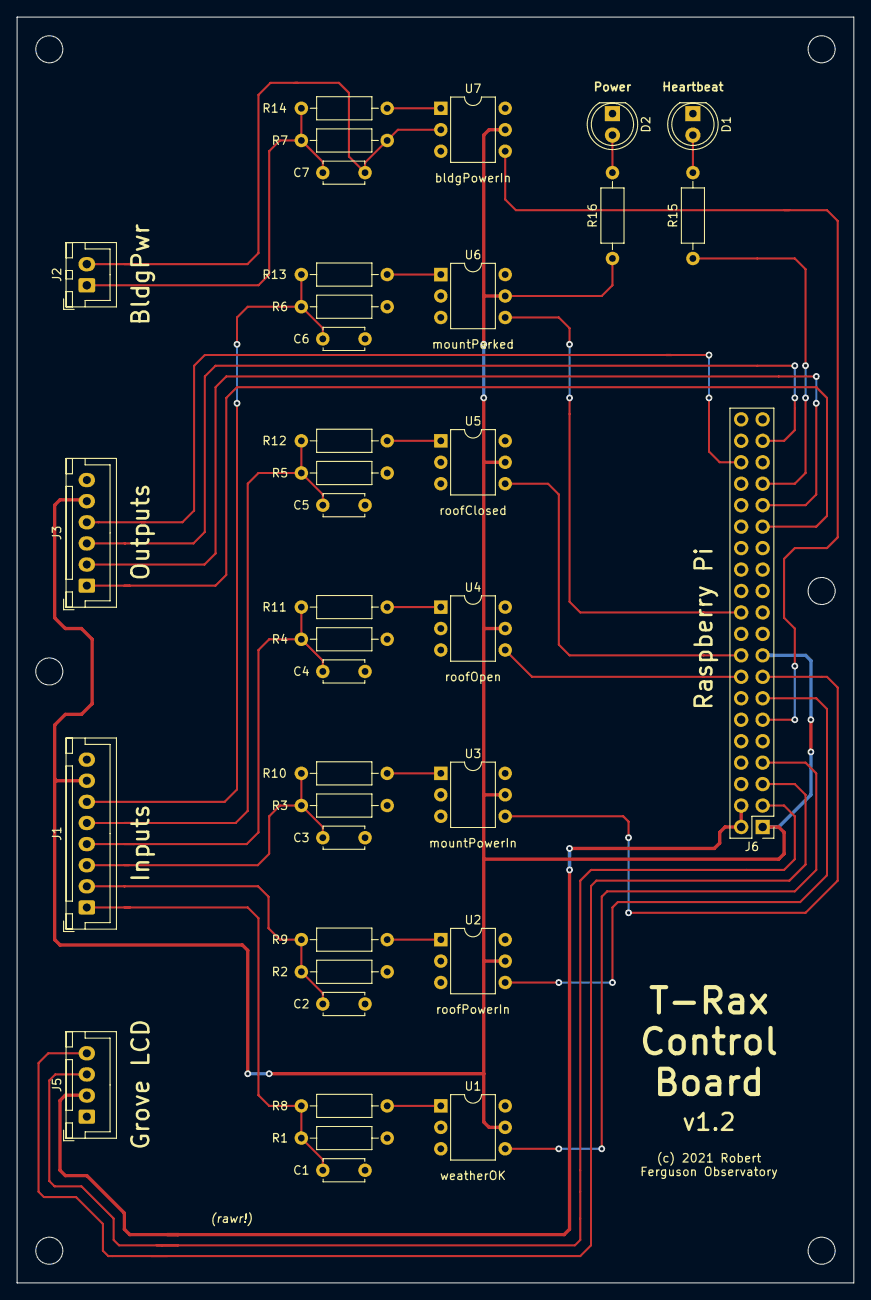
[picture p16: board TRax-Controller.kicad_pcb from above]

Board: 2 copper layers, 99.1 x 149.9 mm, 37 parts (0 on the bottom side), 34 nets.

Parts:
C1, C2, C3, C4, C5, C6, C7: 1000; C_Disc_D4.7mm_W2.5mm_P5.00mm
D1: Green; LED_D5.0mm
D2: Red; LED_D5.0mm
J1: Inputs; JST_XH_B8B-XH-A_1x08_P2.50mm_Vertical
J2: BldgPwr; JST_XH_B2B-XH-A_1x02_P2.50mm_Vertical
J3: Outputs; JST_XH_B6B-XH-A_1x06_P2.50mm_Vertical
J5: Grove LCD; JST_XH_B4B-XH-A_1x04_P2.50mm_Vertical
J6: Raspberry Pi Header; PinHeader_2x20_P2.54mm_Vertical
R1, R2, R3, R4, R5, R6, R7: 10K; R_Axial_DIN0207_L6.3mm_D2.5mm_P10.16mm_Horizontal
R8, R9, R10, R11, R12, R13, R14: 1K; R_Axial_DIN0207_L6.3mm_D2.5mm_P10.16mm_Horizontal
R15, R16: 330; R_Axial_DIN0207_L6.3mm_D2.5mm_P10.16mm_Horizontal
U1, U2, U3, U4, U5, U6, U7: 4N25; DIP-6_W7.62mm

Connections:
+3V3: J1.7, J3.5, J6.1, J6.17, R16.1, U1.5, U2.5, U3.5, U4.5, U5.5, U6.5, U7.5
+5V: J5.2, J6.2, J6.4
GND: C1.2, C2.2, C3.2, C4.2, C5.2, C6.2, D1.1, D2.1, J1.8, J3.6, J5.1, J6.6, J6.9, J6.14, J6.20, J6.25, J6.30, J6.34, J6.39, R1.2, R2.2, R3.2, R4.2, R5.2, R6.2, U1.2, U2.2, U3.2, U4.2, U5.2, U6.2
unnamed: C1.1, J1.1, R1.1, R8.2
unnamed: C2.1, J1.2, R2.1, R9.2
unnamed: C3.1, J1.3, R3.1, R10.2
unnamed: C4.1, J1.4, R4.1, R11.2
unnamed: C5.1, J1.5, R5.1, R12.2
unnamed: C6.1, J1.6, R6.1, R13.2
unnamed: C7.1, J2.1, R7.1, R14.2
unnamed: C7.2, J2.2, R7.2, U7.2
unnamed: D1.2, R15.2
unnamed: D2.2, R16.2
unnamed: J3.1, J6.29
unnamed: J3.2, J6.31
unnamed: J3.3, J6.37
unnamed: J3.4, J6.36
unnamed: J5.3, J6.3
unnamed: J5.4, J6.5
unnamed: J6.7, U1.4
unnamed: J6.11, U7.4
unnamed: J6.13, U2.4
unnamed: J6.15, U3.4
unnamed: J6.16, U4.4
unnamed: J6.18, U5.4
unnamed: J6.22, U6.4
unnamed: J6.33, R15.1
unnamed: R8.1, U1.1
unnamed: R9.1, U2.1
unnamed: R10.1, U3.1
unnamed: R11.1, U4.1
unnamed: R12.1, U5.1
unnamed: R13.1, U6.1
unnamed: R14.1, U7.1

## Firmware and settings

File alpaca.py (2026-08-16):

#!/usr/bin/python3
"""
Simple ASCOM Alpaca-compatible dome controller interface for T-Rax.

This implements a minimal subset of the Alpaca JSON HTTP API sufficient
to control the roll-off roof as a dome shutter: core info endpoints,
shutter Open/Close, and the ``Can...`` capability endpoints (we return
false for rotation-related capabilities since the roof does not rotate).

The class registers Flask routes on construction. It uses the existing
`browser` and `device` modules to perform actions and to check safety
conditions used elsewhere in the project.

Interface notes (ASCOM Alpaca compliance)
-----------------------------------------
A real ASCOM/Alpaca client (e.g. NINA) requires a specific contract that
the earlier version of this file did not fully satisfy.  The pieces that
were folded in from the reference driver (`ALPACA_Dome_Driver-c.py`) are:

* ``CanSetShutter`` returns ``True`` -- a client will not expose the
  Open/Close Shutter buttons unless the driver advertises this.
* ``ShutterStatus`` uses the real ASCOM ``ShutterState`` enumeration
  (0=Open, 1=Closed, 2=Opening, 3=Closing, 4=Error).  The previous code
  used a home-grown mapping (2=Open) that collides with the ASCOM value
  for "Opening".
* ``OpenShutter``/``CloseShutter`` (and ``Connected``/``AbortSlew``) are
  ASCOM *methods*, invoked with HTTP ``PUT``; parameters such as
  ``ClientTransactionID`` arrive in the form body rather than the query
  string.
* The standard Alpaca management API (``/management/apiversions``,
  ``/management/v1/description``, ``/management/v1/configureddevices``).

Unlike the reference driver -- which blocks the request with ``sleep()``
while it fakes roof motion -- ASCOM methods must return promptly and let
the client poll ``ShutterStatus``.  We keep the project's existing
non-blocking design: the command starts the roof and a background watcher
thread updates the tracked status when the roof reaches its end stop.
"""

import itertools
import json
import logging
import socket
import struct
import threading
import time

import flask

import browser
import device
import util

ROOF_STATE_TIMEOUT = 60
ROOF_STATE_POLL_INTERVAL = 0.5
ROOF_POWER_SETTLE_DELAY = 1.0
DISCOVERY_MULTICAST_GROUP = '239.255.255.250'
DISCOVERY_MULTICAST_PORT = 32227

# HTTP port the Flask app (and therefore the Alpaca API) listens on. This is
# what the UDP discovery responder advertises to clients.
ALPACA_HTTP_PORT = 5000

DRIVER_VERSION = '1.1.0'

# ASCOM error number for a property/method that is part of the interface but
# not implemented by this driver (e.g. dome rotation on a shutter-only roof).
NOT_IMPLEMENTED = 0x400

# ASCOM ShutterState enumeration (Dome.ShutterStatus). These values are part
# of the wire protocol -- clients interpret them literally, so they must match
# the ASCOM standard exactly.
SHUTTER_OPEN = 0
SHUTTER_CLOSED = 1
SHUTTER_OPENING = 2
SHUTTER_CLOSING = 3
SHUTTER_ERROR = 4


class Alpaca:
    """Register a minimal Alpaca dome controller on a Flask app.

    Example:
        Alpaca(app, device_number=0)
    """

    _txid_counter = itertools.count(1)

    def __init__(self, app, device_number=0, base_path='/api/v1'):
        self.app = app
        self.device_number = int(device_number)
        self.base = base_path.rstrip('/')
        # Tracked shutter motion. `_shutter_status` holds the in-flight
        # Opening/Closing direction (or a terminal value set by a watcher);
        # `_lock` serialises command acceptance and state transitions, and
        # `_motion_gen` tags each move so a superseded watcher goes inert.
        self._shutter_status = None
        self._lock = threading.Lock()
        self._motion_gen = 0
        # True while a move is reserved but its preflight (park check + toggle)
        # has not yet confirmed the roof is actually moving.
        self._move_pending = False
        # Register routes
        prefix = self._prefix()

        # Core device metadata
        app.add_url_rule(prefix + '/connected', endpoint=prefix + '_connected', view_func=self._connected, methods=['GET', 'PUT'])
        app.add_url_rule(prefix + '/name', endpoint=prefix + '_name', view_func=self._name, methods=['GET'])
        app.add_url_rule(prefix + '/description', endpoint=prefix + '_description', view_func=self._description, methods=['GET'])
        app.add_url_rule(prefix + '/driverinfo', endpoint=prefix + '_driverinfo', view_func=self._driverinfo, methods=['GET'])
        app.add_url_rule(prefix + '/driverversion', endpoint=prefix + '_driverversion', view_func=self._driverversion, methods=['GET'])
        # ASCOM common properties a compliant client queries on connect.
        app.add_url_rule(prefix + '/interfaceversion', endpoint=prefix + '_interfaceversion', view_func=self._interfaceversion, methods=['GET'])
        app.add_url_rule(prefix + '/supportedactions', endpoint=prefix + '_supportedactions', view_func=self._supportedactions, methods=['GET'])
        # ASCOM common methods. Unsupported here, but they must return the
        # standard not-implemented envelope (not a bare 404) for conformance
        # tools and clients that probe them.
        for meth in ('action', 'commandblind', 'commandbool', 'commandstring'):
            app.add_url_rule(prefix + '/' + meth, endpoint=prefix + '_' + meth, view_func=self._not_impl_view(meth), methods=['GET', 'POST', 'PUT'])

        # Capability flags. The roof is a shutter-only dome: it can set the
        # shutter but cannot rotate, slave, park or find home.
        app.add_url_rule(prefix + '/cansetshutter', endpoint=prefix + '_cansetshutter', view_func=self._cansetshutter, methods=['GET'])
        app.add_url_rule(prefix + '/cansyncazimuth', endpoint=prefix + '_cansyncazimuth', view_func=self._cansyncazimuth, methods=['GET'])
        app.add_url_rule(prefix + '/canrotate', endpoint=prefix + '_canrotate', view_func=self._canrotate, methods=['GET'])
        app.add_url_rule(prefix + '/canpark', endpoint=prefix + '_canpark', view_func=self._canpark, methods=['GET'])
        app.add_url_rule(prefix + '/canfindhome', endpoint=prefix + '_canfindhome', view_func=self._canfindhome, methods=['GET'])

        # Advertising InterfaceVersion 2 promises the whole IDomeV2 contract, so
        # the remaining rotation/park members must exist rather than 404. For a
        # shutter-only roof the capability flags are all false, the boolean
        # state properties report false, and the numeric position properties
        # and rotation/park methods return a proper ASCOM "not implemented"
        # error (better than a bare Flask 404 a strict client may reject on).
        for cap in ('cansetaltitude', 'cansetazimuth', 'cansetpark', 'canslave'):
            app.add_url_rule(prefix + '/' + cap, endpoint=prefix + '_' + cap, view_func=self._const_view(False), methods=['GET'])
        for prop in ('athome', 'atpark'):
            app.add_url_rule(prefix + '/' + prop, endpoint=prefix + '_' + prop, view_func=self._const_view(False), methods=['GET'])
        # Slewing is derived from the live shutter status (see _slewing).
        app.add_url_rule(prefix + '/slewing', endpoint=prefix + '_slewing', view_func=self._slewing, methods=['GET'])
        for prop in ('altitude', 'azimuth'):
            app.add_url_rule(prefix + '/' + prop, endpoint=prefix + '_' + prop, view_func=self._not_impl_view(prop), methods=['GET'])
        for meth in ('findhome', 'park', 'setpark', 'slewtoaltitude', 'slewtoazimuth', 'synctoazimuth'):
            app.add_url_rule(prefix + '/' + meth, endpoint=prefix + '_' + meth, view_func=self._not_impl_view(meth), methods=['GET', 'POST', 'PUT'])
        # Slaved is readable (always false) and writable only to false.
        app.add_url_rule(prefix + '/slaved', endpoint=prefix + '_slaved', view_func=self._slaved, methods=['GET', 'PUT'])

        # Basic discovery / service info (rooted at the base path)
        app.add_url_rule(self.base + '/discovery', endpoint=prefix + '_discovery', view_func=self._discovery, methods=['GET'])
        app.add_url_rule(self.base + '/apiversion', endpoint=prefix + '_apiversion', view_func=self._apiversion, methods=['GET'])

        # Standard Alpaca management API (server-global, rooted at /management)
        app.add_url_rule('/management/apiversions', endpoint=prefix + '_management_apiversions', view_func=self._management_apiversions, methods=['GET'])
        app.add_url_rule('/management/v1/description', endpoint=prefix + '_management_description', view_func=self._management_description, methods=['GET'])
        app.add_url_rule('/management/v1/configureddevices', endpoint=prefix + '_management_configureddevices', view_func=self._configureddevices, methods=['GET'])
        # Backward-compatible aliases some clients probe under the API base
        app.add_url_rule(self.base + '/management/apiversions', endpoint=prefix + '_management_apiversions_prefixed', view_func=self._management_apiversions, methods=['GET'])
        app.add_url_rule(self.base + '/configureddevices', endpoint=prefix + '_configureddevices', view_func=self._configureddevices, methods=['GET'])
        self._start_multicast_responder()

        # Shutter control. Open/Close are ASCOM methods invoked with PUT; we
        # also accept GET/POST so the endpoints can be exercised from a browser.
        app.add_url_rule(prefix + '/openshutter', endpoint=prefix + '_openshutter', view_func=self._openshutter, methods=['GET', 'POST', 'PUT'])
        app.add_url_rule(prefix + '/closeshutter', endpoint=prefix + '_closeshutter', view_func=self._closeshutter, methods=['GET', 'POST', 'PUT'])
        app.add_url_rule(prefix + '/abortslew', endpoint=prefix + '_abortslew', view_func=self._abortslew, methods=['GET', 'POST', 'PUT'])
        app.add_url_rule(prefix + '/shutterstatus', endpoint=prefix + '_shutterstatus', view_func=self._shutterstatus, methods=['GET'])

    def _prefix(self):
        # e.g. /api/v1/dome/0
        return '{}/dome/{}'.format(self.base, self.device_number)

    def _next_txid(self):
        return next(Alpaca._txid_counter)

    def _client_txid(self):
        """Read ClientTransactionID from the query string (GET) or form (PUT)."""
        for src in (flask.request.args, flask.request.form):
            raw = src.get('ClientTransactionID')
            if raw is not None:
                try:
                    return int(raw)
                except (TypeError, ValueError):
                    return 0
        return 0

    def _resp(self, value=None, error_number=0, error_message=''):
        resp = {
            'ClientTransactionID': self._client_txid(),
            'ServerTransactionID': self._next_txid(),
            'ErrorNumber': int(error_number),
            'ErrorMessage': error_message,
        }
        # ASCOM property reads carry a Value; method (PUT) responses do not.
        if value is not None:
            resp['Value'] = value
        return flask.jsonify(resp)

    def _const_view(self, value):
        """Build a zero-arg GET handler that always returns a constant value."""
        return lambda: self._resp(value)

    def _not_impl_view(self, name):
        """Build a handler for an interface member this driver does not implement."""
        return lambda: self._resp(error_number=NOT_IMPLEMENTED, error_message='{} is not implemented'.format(name))

    def _slaved(self):
        # A roll-off roof cannot slave to the telescope. Report false, and
        # accept a PUT only when it sets Slaved=false (a no-op).
        if flask.request.method == 'PUT':
            want = flask.request.form.get('Slaved', 'false').lower() == 'true'
            if want:
                return self._resp(error_number=NOT_IMPLEMENTED, error_message='Slaving is not implemented')
            return self._resp()
        return self._resp(False)

    # Core info endpoints
    def _connected(self):
        # A client "connects" by PUTting Connected=true. We are stateless and
        # always available, so we simply acknowledge the request.
        if flask.request.method == 'PUT':
            state = flask.request.form.get('Connected', 'false').lower() == 'true'
            logging.info('Alpaca: client set Connected=%s', state)
            return self._resp()
        return self._resp(True)

    def _name(self):
        return self._resp('T-Rax Roof Dome')

    def _description(self):
        return self._resp('T-Rax roll-off roof presented as an Alpaca dome (shutter only)')

    def _driverinfo(self):
        return self._resp('T-Rax Alpaca dome bridge to the roll-off roof controller')

    def _driverversion(self):
        return self._resp(DRIVER_VERSION)

    def _interfaceversion(self):
        # We implement the classic IDomeV2 property/method set.
        return self._resp(2)

    def _supportedactions(self):
        # No device-specific custom actions are exposed.
        return self._resp([])

    # Capability endpoints
    def _cansetshutter(self):
        # The roof *is* the shutter, so we can open and close it.
        return self._resp(True)

    def _cansyncazimuth(self):
        return self._resp(False)

    def _canrotate(self):
        return self._resp(False)

    def _canpark(self):
        # No dedicated park functionality for the roof
        return self._resp(False)

    def _canfindhome(self):
        return self._resp(False)

    def _discovery_data(self):
        ip_address = util.get_ip()
        return {
            'DeviceType': 'dome',
            'DeviceNumber': self.device_number,
            'DeviceName': 'T-Rax Roof Dome',
            'Connected': True,
            'BaseURL': self._prefix(),
            'APIVersion': 1,
            'ServerName': 'T-Rax',
            'Vendor': 'Robert Ferguson Observatory',
            'Manufacturer': 'Robert Ferguson Observatory',
            'IPAddress': ip_address,
            'HTTPPort': ALPACA_HTTP_PORT,
            'SupportedApiVersions': [1],
            'Description': 'ASCOM Alpaca dome shutter interface',
        }

    def _discovery(self):
        return self._resp([self._discovery_data()])

    def _apiversion_data(self):
        return {
            'AlpacaVersion': 1,
            'CurrentApiVersion': 1,
            'SupportedApiVersions': [1],
            'ServerName': 'T-Rax',
            'Vendor': 'Robert Ferguson Observatory',
            'ServerBaseURL': self.base,
        }

    def _apiversion(self):
        return self._resp(self._apiversion_data())

    def _management_apiversions(self):
        """Return list of supported Alpaca API versions (management discovery)."""
        return self._resp([1])

    def _management_description(self):
        """Return the server description block for management discovery."""
        return self._resp({
            'ServerName': 'T-Rax',
            'Manufacturer': 'Robert Ferguson Observatory',
            'ManufacturerVersion': DRIVER_VERSION,
            'Location': 'RFO, Kenwood CA',
        })

    def _configureddevices(self):
        # Return list of configured devices on this server
        devices = [
            {
                'DeviceName': 'T-Rax Roof Dome',
                'DeviceType': 'Dome',
                'DeviceNumber': self.device_number,
                'UniqueID': 'uuid:trax:dome:{}'.format(self.device_number),
            }
        ]
        return self._resp(devices)

    def _format_discovery_response(self):
        # Per the Alpaca discovery specification the UDP reply is a small JSON
        # document naming the HTTP port the Alpaca API is served on.
        try:
            payload = {'AlpacaPort': ALPACA_HTTP_PORT}
            return json.dumps(payload).encode('utf-8')
        except Exception as e:
            logging.error('Failed to format JSON discovery response: %s', e)
            return b''

    def _multicast_responder(self):
        # Listen for UDP broadcast discovery probes on the discovery port.
        sock = socket.socket(socket.AF_INET, socket.SOCK_DGRAM, socket.IPPROTO_UDP)
        sock.setsockopt(socket.SOL_SOCKET, socket.SO_REUSEADDR, 1)
        try:
            if hasattr(socket, 'SO_REUSEPORT'):
                sock.setsockopt(socket.SOL_SOCKET, socket.SO_REUSEPORT, 1)
        except Exception:
            pass
        # Allow receiving broadcasts
        try:
            sock.setsockopt(socket.SOL_SOCKET, socket.SO_BROADCAST, 1)
        except Exception:
            pass
        try:
            sock.bind(('', DISCOVERY_MULTICAST_PORT))
        except OSError as e:
            logging.error('Alpaca broadcast bind failed: %s', e)
            return

        logging.info('Alpaca broadcast responder listening on port %s', DISCOVERY_MULTICAST_PORT)
        while True:
            try:
                data, addr = sock.recvfrom(1024)
                if not data:
                    continue
                text = data.decode('utf-8', errors='ignore')
                # The official Alpaca discovery probe is the ASCII string
                # "alpacadiscovery1".
                upper = text.upper()
                if 'ALPACADISCOVERY' in upper:
                    logging.info('Received discovery request from %s', addr)
                    response = self._format_discovery_response()
                    sock.sendto(response, addr)
            except Exception as e:
                logging.error('Alpaca multicast responder error: %s', e)

    def _start_multicast_responder(self):
        thread = threading.Thread(target=self._multicast_responder, daemon=True)
        thread.start()

    # Shutter state mapping
    def _get_shutter_state(self):
        # A tracked move in progress takes precedence over the end-stop sensors:
        # the origin sensor can stay asserted until the motor physically starts,
        # so reporting the sensor here would momentarily look like a completed
        # terminal state. While Opening/Closing the watcher owns the transition
        # to the terminal value once the target sensor asserts.
        status = self._shutter_status
        if status in (SHUTTER_OPENING, SHUTTER_CLOSING):
            return status
        # At rest the end-stop sensors are authoritative (this also reflects
        # motion started outside this Alpaca instance, e.g. via /startstop).
        try:
            open_on = device.Gpio.open.isOn()
            close_on = device.Gpio.close.isOn()
        except Exception:
            return SHUTTER_ERROR
        if open_on and close_on:
            # Both sensors active is a fault ("confused") condition.
            return SHUTTER_ERROR
        if open_on:
            return SHUTTER_OPEN
        if close_on:
            return SHUTTER_CLOSED
        # Neither sensor active and no tracked move: the roof is stuck midway.
        return SHUTTER_ERROR

    def _start_roof_state_watcher(self, gen, target_sensor, success_fn, action_name):
        # `gen` tags this watcher with the motion generation it belongs to. If a
        # newer move (or rollback) bumps self._motion_gen, this watcher becomes
        # stale and must not touch the shutter state -- otherwise a lingering
        # opening watcher could fire _on_open_complete during a later close,
        # cutting roof power and enabling mount power mid-close.
        def watcher():
            deadline = time.time() + ROOF_STATE_TIMEOUT
            try:
                while time.time() < deadline:
                    if self._motion_gen != gen:
                        return  # superseded by a newer move
                    if target_sensor.isOn():
                        with self._lock:
                            if self._motion_gen != gen:
                                return
                            success_fn()
                        return
                    time.sleep(ROOF_STATE_POLL_INTERVAL)
            except Exception as e:
                # A transient sensor/GPIO read (or completion callback) failure
                # must not leave the daemon thread dead with the status stuck
                # Opening/Closing forever. Fall through to the error transition.
                logging.error('Alpaca: roof %s watcher error: %s', action_name, e)
                with self._lock:
                    if self._motion_gen == gen:
                        self._shutter_status = SHUTTER_ERROR
                return
            with self._lock:
                if self._motion_gen != gen:
                    return
                self._shutter_status = SHUTTER_ERROR
            browser.browser.sendNotice(
                "Timeout waiting for roof {} after {} seconds".format(action_name, ROOF_STATE_TIMEOUT),
                log='ERROR'
            )

        thread = threading.Thread(target=watcher, daemon=True)
        thread.start()

    # Note: _on_open_complete / _on_close_complete run while self._lock is held
    # (called from the watcher) so the status update and GPIO actuation are
    # atomic with respect to command acceptance.
    def _on_open_complete(self):
        # GPIO actuation (roof power off, mount power on) is handled by
        # browser.Browser._on_open_complete via the move watcher started by doOpen().
        self._shutter_status = SHUTTER_OPEN

    def _on_close_complete(self):
        # GPIO actuation (roof power off) is handled by
        # browser.Browser._on_close_complete via the move watcher started by doClose().
        self._shutter_status = SHUTTER_CLOSED

    def _shutterstatus(self):
        return self._resp(self._get_shutter_state())

    def _slewing(self):
        # Slewing reports whether any dome component is moving. The roof only
        # moves while the shutter is opening or closing.
        return self._resp(self._get_shutter_state() in (SHUTTER_OPENING, SHUTTER_CLOSING))
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

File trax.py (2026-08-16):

#!/usr/bin/python3
#
# T-Rax roof controller for the Raspberry Pi
#
# This is a roll-off roof controller specifically designed and built for
# Robert Ferguson Observatory (https://rfo.org) but the code will hopefully
# be generic enough that it can be adapted for other roll-off roofs.
# See README.md for details.

import argparse
import datetime
import errno
import fcntl
import logging
import os
import signal
import sys
import threading

import browser
import device
import test_mode
import util
import sse
import alpaca

import flask
app = flask.Flask(__name__)

# Register minimal Alpaca dome interface (shutter-only)
alpaca.Alpaca(app, device_number=0, base_path='/api/v1')

try:
    with open(os.path.join(os.path.dirname(os.path.abspath(__file__)), 'VERSION')) as _vf:
        version = _vf.read().strip()
except OSError:
    version = 'unknown'
statusInterval = 60     # Seconds between status updates without input changes
lockfile = 0            # Global so when we lock we keep it
lockfilename = '/tmp/trax.lock'

def initialize():
    # Parse command line args
    default_logfile = '/var/log/trax.log'
    parser = argparse.ArgumentParser(description='T-Rax roof controller.')
    parser.add_argument('--test-mode', dest='test_mode', action='store_true', help='enter test mode')
    parser.add_argument('--simulator', dest='simulator', action='store_true', help='adjust timings for T-Rax simulator')
    parser.add_argument('--debug', dest='debug', action='store_true', help='include DEBUG messages in logs')
    parser.add_argument('--log-file', '-L', dest='logfile', action='store', help='log filename (default {})'.format(default_logfile))
    args = parser.parse_args()

    # Acquire an exclusive lock
    global lockfile
    try:
        lockfile = open(lockfilename, "a+")
        if (lockfile):
            fcntl.lockf(lockfile, fcntl.LOCK_EX|fcntl.LOCK_NB)
    except OSError as e:
        if (e.errno == errno.EACCES or e.errno == errno.EAGAIN):
            sys.exit("ABORT! trax is already running!")

    # Annotate the lock file with our pid
    lockfile.seek(0)
    lockfile.truncate()
    lockfile.write("{}\n".format(os.getpid()))
    lockfile.flush()

    # Set up logging
    # TODO consider using flask logging interface https://flask.palletsprojects.com/en/1.1.x/logging/
    loggingConfig = dict(
        format = "%(asctime)s [%(levelname)s] %(message)s",
        datefmt = "%Y-%m-%d %H:%M:%S",
        level = logging.DEBUG if (args.debug) else logging.INFO)
    if (sys.stdin.isatty() and not args.logfile):
        print("TTY detected; logging to stderr")
    else:
        loggingConfig['filename'] = args.logfile if args.logfile else default_logfile;
    logging.basicConfig(**loggingConfig)
    logging.basicConfig(**loggingConfig)
    # Ensure DEBUG logs actually appear when requested: set root and common
    # framework loggers to DEBUG when `--debug` is used.
    if (args.debug):
        logging.getLogger().setLevel(logging.DEBUG)
        try:
            logging.getLogger('werkzeug').setLevel(logging.DEBUG)
        except Exception:
            pass
        try:
            logging.getLogger('flask.app').setLevel(logging.DEBUG)
        except Exception:
            pass
        logging.debug('Debug logging enabled')

    logging.info("Initializing T-Rax for the Raspberry Pi {}".format(version))
    if (args.simulator):
        logging.info("Adjusting timings for simulator")

    # Initialize devices
    gpio = device.Gpio(args.simulator)
    logging.info(device.printStatus())

    # Let browser know our version
    browser.browser.setVersion(version)

    # Enter test mode if requested
    if (args.test_mode):
        # TODO: pass in gpio instead of using xxx.by_name
        test = test_mode.TestMode()
        exit  # Test mode should not return, but just in case


#
# Register URL callbacks
#

@app.route('/')
def top():
    return flask.render_template('trax.html')

@app.route('/connect', methods=['GET'])
def connect():
    """Browser connected to T-Rax; dispatch welcome message and connect brower to SSE stream"""
    logging.info("Browser connected from {}".format(flask.request.remote_addr))
    threading.Timer(0.5, browser.browser.initialConnect).start()  # Dispatch our welcome connect function
    return flask.Response(sse.sse.stream(), mimetype='text/event-stream')

@app.route('/startstop', methods=['GET'])
def startStop():
    """User pressed the Start/Stop button (legacy; also used for midway/override toggle)"""
    return browser.browser.startStop(app)

@app.route('/open', methods=['GET'])
def openRoof():
    """PHD button: open the roof (full sequence)"""
    return browser.browser.doOpen()

@app.route('/close', methods=['GET'])
def closeRoof():
    """PHD button: close the roof (full sequence)"""
    return browser.browser.doClose()

@app.route('/roofpwr', methods=['GET'])
def roofPwrOnOff():
    return browser.browser.roofPower(app)

@app.route('/mountpwr', methods=['GET'])
def mountPwrOnOff():
    return browser.browser.mountPower(app)

@app.route('/checkpark', methods=['GET'])
def checkPark():
    return browser.browser.checkPark(app)

@app.route('/STOP', methods=['GET'])
def emergencyStop():
    return browser.browser.emergencyStop(app)

@app.route('/override', methods=['GET'])
def doOverride():
    return browser.browser.doOverride(app)


if __name__ == '__main__':
    initialize()
    device.perSecond()
    app.run('0.0.0.0', 5000)

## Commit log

2021-03-16 split Sensor and Control into device.py
2021-03-16 moved printStatus to util.py
2021-03-20 cleaned up references; moved printStatus to device; other misc
2021-03-29 mixed fobOutput pin
2021-04-04 switched to threading rather than signals
2021-04-04 switched from custom logger.py to standard logging module
2021-04-08 checkpoint: implemented JS update_indicator(); moved updates to printStatus()
2021-04-10 made buttons work (with placeholder functions)
2021-04-11 button callbacks functioning but no safety controls
2021-04-12 restored weather pin... again! ???
2021-04-12 replicated Arduino safety logic
2021-04-12 device callbacks update browser status and log
2021-04-13 Refactored devices to all be inside Gpio class
2021-04-14 add isParked() laser logic
2021-04-16 added park laser check and decay
2021-04-17 split out checkPark() and isParked(); switch to park enum
2021-04-27 added 3D Print plans from Jay
    [rfo.stl]
2021-05-12 added KiCad files (schematics, pcb layout)
    [TRax-Controller.kicad_pcb, TRax-Controller.sch, TRax-Relays.kicad_pcb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]
2021-05-12 added KiCad exceptions
2021-05-12 renamed pcb directory
    [TRax-Controller.kicad_pcb, TRax-Controller.sch, TRax-Relays.kicad_pcb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]
2021-05-12 bumped schematic version, cleaned up
    [TRax-Controller.sch]
2021-05-12 added block diagram placeholders
    [TRax-BlockDiagram.sch]
2021-05-12 added KiCad readme
2021-05-17 add file locking to prevent multiple copies
    [trax.py]
2021-05-27 ignore Gerber files
2021-05-27 switch to 6P6C connectors; misc cleanup
    [TRax-Relays.sch]
2021-05-27 relays schematic v1.2b
2021-06-24 pulled custom relay symbol into library
    [TRax-Relays.sch]
2021-07-03 mount and roof should not be reverse logic
    [device.py]
2021-07-07 removed pedantic power checks
2021-07-17 fix red/black wiring on input RJ11s
    [TRax-Relays.sch]
2021-08-22 v1.0.5: in emergency override, checkPark toggles laser indefinitely, and updateBrowser reports actual park position
2021-08-23 in emergency override, checkPark toggles laser indefinitely, and updateBrowser reports actual park position
2021-09-28 Revert "bump version"
    This reverts commit 960fc378857c819416aefac2ec4f12e1e89098eb.
    [trax.py]
2021-09-28 replace toggleThrice() with toggleFob()
    [browser.py]
2021-09-28 removed toggleThrice(); added logging and notification to toggleFob(); fixed bugs
    [device.py]
2021-09-28 RELEASE v.1.0.6: Replace toggleThrice() with fob.toggleFob(), using callbacks instead of a timer loop
    [trax.py]
2021-10-17 Fixed toggleFob() roof logic; Added "confused" roof state
    [browser.py]
2021-10-18 merged all there schematics into one
    [Relays.sch, TRax-Controller.kicad_pcb, TRax-Controller.sch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]
2021-10-18 Updated revision history and printed to pdf
2021-10-18 Updated revision history
    [TRax-Controller.sch, TRax-LaserParkDetector.sch, TRax-Relays.sch]
2021-10-18 cleaned up pre-merge docs
    [TRax-BlockDiagram.sch, TRax-Relays.kicad_pcb, TRax-Relays.sch]
2021-10-31 updated schematic (v1.7) direct wire fob isolator to fob tigger
    [TRax-Controller.sch, TRax-LaserParkDetector.sch, TRax-Relays.sch]
2023-06-21 bumped version to 1.0.8rc0; implement 120 second timeout for laser
2023-06-22 bumped version to 1.0.8; fixed laser timeout for Emergency Override
    [browser.py, device.py, trax.py]
2024-03-01 add Laser Park Detector board layout
    [TRax-LaserParkDetector-B_Cu.gbr, TRax-LaserParkDetector-B_Mask.gbr, TRax-LaserParkDetector-B_Paste.gbr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]
2026-05-30 add a minimal ASCOM Alpaca dome driver to control the roof (with GitHub copilot GPT-5 help)
2026-06-13 alpaca: add roof and mount power logic to _{open,close}shutter()
2026-06-14 alpaca: claude was hallucinating multicast; switch to udp broadcast
2026-06-14 fix debug logging (I hope!)
    [trax.py]
2026-08-02 alpaca: complete ASCOM shutter interface for dome clients
    Fold the ASCOM-compliant interface contract from the reference driver
    (ALPACA_Dome_Driver-c.py) into the class-based Alpaca dome bridge so real
    ASCOM/Alpaca clients (e.g. NINA) can drive the roll-off roof as a
    shutter-only dome. The existing hardware wiring (browser.startStop safety
    interlocks, device.Gpio control, non-blocking roof-state watcher threads)
    is preserved.
    Interface fixes and additions:
    - CanSetShutter returns True (clients require this to offer shutter control)
    - ShutterStatus now uses the real ASCOM ShutterState enum
    (0=Open, 1=Closed, 2=Opening, 3=Closing, 4=Error); the previous mapping
    reported "open" as 2, which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
    [alpaca.py, test_alpaca.py]
2026-08-02 alpaca: add common properties and guard in-flight shutter commands
    Address review feedback on the ASCOM interface:
    - Register the ASCOM common properties InterfaceVersion (2) and
    SupportedActions ([]). A standards-compliant client queries these on
    connect; without handlers Flask returned a bare 404, which can make a
    client reject the device before reaching the shutter controls.
    - The roof is driven by a single START/STOP toggle, so issuing a second
    shutter command while it is moving would fall into browser.startStop's
    midway branch and toggle the fob once, stopping the roof (and an
    opposite-direction command stopped rather than reversed). OpenShutter/
    CloseShutter now treat a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
    [alpaca.py, test_alpaca.py]
2026-08-02 alpaca: honest AbortSlew, drop divergent shutterstate alias
    Address further review feedback:
    - AbortSlew no longer reports a false success. A roll-off roof cannot
    safely honour a remote mid-travel abort, so returning ErrorNumber 0
    told a client motion had stopped when it had not. It now returns an
    explicit ASCOM "not implemented" error (0x400); the physical Emergency
    Stop remains the path for a genuine halt.
    - Remove the /shutterstate alias. It was presented as backward compatible
    but routing it to the ASCOM handler changed its wire values (open was 2,
    now 0), which legacy automation could misread as the old "unknown"
    state. This Alpaca interface is unreleased, so rather than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
    [alpaca.py, test_alpaca.py]
2026-08-02 alpaca: refuse shutter commands from non-terminal roof positions
    - OpenShutter/CloseShutter now only start a move from the opposite
    terminal end-stop state (fully closed for open, fully open for close).
    The previous guards only caught moves this Alpaca instance was tracking,
    so a roof left midway by the browser /startstop path, a service restart,
    or a watcher timeout (where _shutter_status is None/ERROR) still reached
    browser.startStop()'s directionless midway toggle, which could stop or
    reverse a moving roof and then be mislabelled as opening. Such
    unknown/in-motion positions are now refused. A move already tracked in
    the requested direction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
    [alpaca.py, test_alpaca.py]
2026-08-02 alpaca: serialize shutter moves with a locked, generation-tracked state machine
    The shutter handling had several concurrency/state races flagged in review.
    Rework it around a lock, a motion-generation counter, and a shared
    _begin_move() helper:
    - Reserve the Opening/Closing status inside a critical section *before* the
    blocking park check and startStop(), so an overlapping retry can no longer
    slip past the idempotency guard and fire a second START/STOP toggle that
    stops the roof. If the blocking work fails, the reservation is rolled back
    under the generation guard.
    - Tag every move with an incrementing generation and pass it to the roof-
    state watcher. A watcher whose generation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
    [alpaca.py, test_alpaca.py]
2026-08-02 alpaca: roll back reserved moves on failure; don't ack pending duplicates
    Two remaining issues in the reserve-before-blocking flow:
    - If the post-reservation preflight raised (checkParked/GPIO/startStop
    throwing), the move stayed reserved as Opening/Closing with no watcher,
    so the instance reported motion forever and rejected later commands. The
    blocking sequence is now wrapped so any exception rolls the reservation
    back (generation-guarded) and returns an error envelope.
    - A duplicate command arriving during the multi-second park check was
    acknowledged as success merely because the first request had reserved the
    moving status -- even though that first request could still fail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
    [alpaca.py, test_alpaca.py]
2026-08-02 alpaca: keep moves tracked on watcher failure; guard watcher sensor reads
    Two failure paths that occur after the fob has actuated:
    - Watcher-startup failure no longer rolls the move back. Once
    browser.startStop() returns OK the fob has been toggled and the roof is
    physically moving, so rolling the reservation back would let an immediate
    retry fire a second toggle and stop the roof. The rollback try/except now
    covers only the pre-actuation preflight; if starting the watcher thread
    then fails, the move is left conservatively tracked as Opening/Closing.
    - The watcher poll loop is wrapped so a raising sensor read (or completion
    callback) transitions the move to the error state inst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
    [alpaca.py, test_alpaca.py]
2026-08-07 add roof power delay before open
2026-08-08 Remove unused DISCOVERY_RESPONSE_ST constant (closes #8)
    Leftover from the SSDP/UPnP reference driver; never referenced anywhere.
2026-08-08 Tighten UDP discovery probe match to ALPACADISCOVERY only (closes #10)
    The previous match also accepted 'M-SEARCH' and bare 'DISCOVERY', both
    carried over from the SSDP/UPnP reference driver. These are not part of
    the Alpaca discovery spec and could cause spurious responses to unrelated
    UDP traffic on port 32227. Match only the official probe string.
    [alpaca.py]
2026-08-08 Make ServerTransactionID increment thread-safe (closes #7)
    The previous bare integer read-modify-write on a class variable was not
    atomic under Flask's multi-threaded request handling. Replace it with
    itertools.count(), whose next() is thread-safe, ensuring unique and
    monotonically increasing ServerTransactionIDs as required by the ASCOM
    Alpaca spec.
    [alpaca.py]
2026-08-08 Propagate startStop() failure reason to Alpaca error message (closes #6)
    browser.startStop() previously returned a bare "ERROR" string on any
    interlock failure, leaving the Alpaca driver to emit a generic "Failed
    to open/close shutter" message that gave NINA no actionable information.
    Return the interlock reason string directly (e.g. "Cannot open roof:
    Weather not OK") so it flows through to the Alpaca ErrorMessage field
    and is visible in the NINA log. Browser behaviour is unchanged: the same
    string was already sent to the SSE notice channel, and any non-"OK"
    return is still treated as a failure by all callers.
    [alpaca.py, browser.py]
2026-08-08 Replace hardcoded override password with SHA-256 file-based check (closes #13)
    Read a SHA-256 hex digest from /etc/trax/override.passwd at startup
    (via setVersion(), which is called after logging is configured). If the
    file is absent or malformed, override mode is disabled entirely and a
    warning is logged. Also removes the log statement that recorded the
    plaintext password on every override attempt.
    To set the password on the Pi:
    python3 -c "import hashlib; print(hashlib.sha256(b'yourpassword').hexdigest())" \
    | sudo tee /etc/trax/override.passwd
    [browser.py]
2026-08-14 Full UI redesign: PHD button, clickable indicators, unified open/close path (closes #4)
    Backend:
    - Add doOpen()/doClose() to Browser: full sequence (safety checks, power
    management, fob toggle, completion watcher that fires GPIO on arrival)
    - Add _on_open_complete()/_on_close_complete() to Browser: turn off roof
    power and (on open) enable mount power when sensor asserts
    - Add roof_move_active flag that blocks concurrent /startstop, /open, /close
    - Rewrite startStop() to delegate to doOpen()/doClose() for terminal states
    - Add /open and /close Flask routes for the PHD button
    - Alpaca _begin_move() now calls browser.doOpen()/doClose() directly; power
    management and park check are handled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
    [alpaca.py, browser.py, test_alpaca.py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]
2026-08-14 Replace ON/OFF button pairs with pill toggle switches; bump to v2.0.0
    Per Dave's PR #23 review: merge the separate Roof/Mount power ON/OFF
    button pairs into the indicator tiles themselves. roof_pwr and mount_pwr
    are now CSS pill toggle switches (green=ON, red=OFF, animated knob) that
    toggle on click. The six button/label divs in the upper-right are removed.
    JS updated to drive toggles via data-state rather than innerHTML.
    [trax.py]
2026-08-14 Fire SSE indicator event from roofPower/mountPower after acting
    Previously the roof_pwr and mount_pwr indicators relied solely on the
    input sensor (roofin/mntin) going high via the hardware relay — which
    never happens in mock mode. Firing the event directly from the handler
    makes the toggle testable locally and gives faster UI feedback on real
    hardware too.
2026-08-16 Layout, toggle feedback, and VERSION file per Dave's PR #23 review
    - Power toggle knob (data-knob) is click-driven; background color (data-state)
    is sensor-driven via updateBrowser(). Before first click, sensor events also
    sync the knob so initial position reflects hardware state.
    - Remove immediate SSE fires from roofPower()/mountPower() — sensor feedback
    loop is the authoritative source of toggle color on real hardware.
    - Spread right-column controls: notice_box +1 text line tall, emergency stop
    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

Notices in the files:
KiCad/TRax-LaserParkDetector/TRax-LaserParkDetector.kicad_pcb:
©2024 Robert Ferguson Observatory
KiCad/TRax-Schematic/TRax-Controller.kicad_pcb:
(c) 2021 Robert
